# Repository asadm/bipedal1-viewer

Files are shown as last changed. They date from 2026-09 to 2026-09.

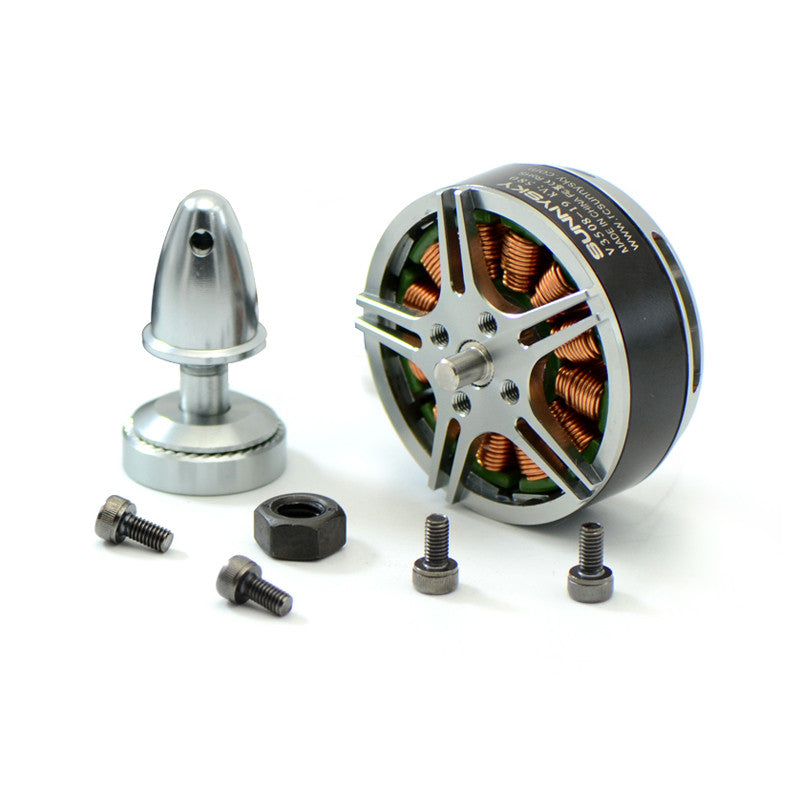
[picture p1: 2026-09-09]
clanky-v2/hardware-references/v3508-4.jpg

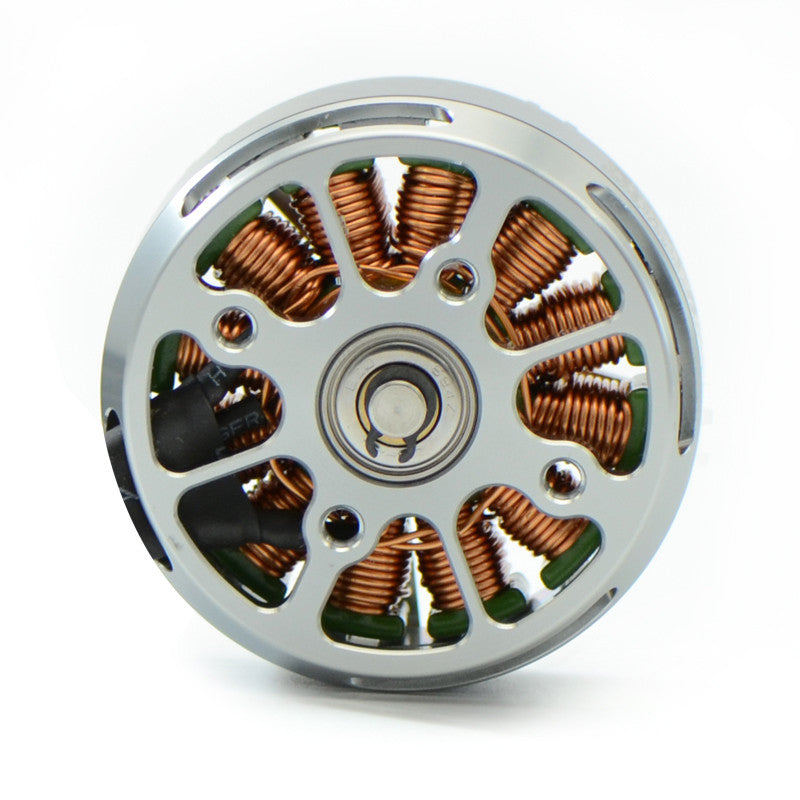
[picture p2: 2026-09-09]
clanky-v2/hardware-references/v3508-3.jpg

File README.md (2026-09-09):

# Clanky robot viewer

Built viewer, CAD assets and simulation replays, automatically updated from the
robot project on each push. `deployment.json` identifies the source revision.

- [Open the current design](https://asadm.github.io/bipedal1-viewer/)
- [Watch learned skills and programmed demos](https://asadm.github.io/bipedal1-viewer/viewer/skills.html)

The robot and policies are simulation prototypes. Physical hardware remains
unqualified; see the validation reports linked from the viewer.

Raw development records and unlinked CAD exports remain in the source robot
repository. `source-files.json` lists the files omitted from this static site.

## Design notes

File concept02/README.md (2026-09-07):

# Enclosed concept 02

[Open the new interactive design](http://127.0.0.1:8765/viewer/enclosed.html). Start the existing local server with `python3 design/viewer/serve.py` if needed. The earlier mechanism viewer remains at `/viewer/`.

This is an actual parametric solid-CAD **appearance and packaging concept** for the enclosed jumping direction. It replaces the open side plates with a rounded body, rear closure, TPU lower wrap, covered arms and an integrated fixed face. It does not yet establish a working jump transmission, balance controller, assembly sequence, strength or environmental rating.

The low pose is nominally **160 × 180 × 180 mm**, and the body rises 50 mm to approximately 230 mm overall. It retains Beni's reference width and compact height, with a shorter body. Tessellated/CAD bounding boxes may include about 0.2 mm tolerance. Every printed shape is checked for a single connected solid and a bounding box within 170 × 170 × 180 mm. Print orientation, support removal and fit still need slicer/prototype work; no functional STLs are released for this revision.

## Inspect

- Drag to orbit, scroll to zoom, right-drag to pan. Front, Side, Top and Fit reset the camera.
- The slider changes the **shared nominal arm angle**, moving the body through 50 mm while the tires stay at ground level. It is not the motor-shaft angle: reduction and spring deflection are unselected.
- Enclosed, Ghost and Cutaway show the outside or internal reservations. Cutaway removes the front shell, impact wrap, visor and right arm enclosure.
- **Locate jump drive** opens the cutaway and highlights the orange package low at the rear of the body.
- **Inside the jump drive** opens an [enlarged functional mechanism sketch](http://127.0.0.1:8765/viewer/drive.html). Crouch / Load / Extend / Retract show prescribed input/output angles. An independent left-arm slider shows that the two spring deflections need not match. A single 3:1 gear stage and helical torsion springs illustrate the force path; their dimensions, total reduction and fit are not selected. Separate damping and final bearing/retention details are not depicted.
- **One-wheel bump** places the left wheel on a 12 mm block while prescribing a level body. This demonstrates independent geometry; it does not demonstrate automatic roll leveling or a solved suspension response.
- Click any part for its role and design status. Wheels and part edges can be toggled.

The orange 34 × 74 × 68 mm volume reserves space for a rotary drive/reduction; it is **not the drawing of a selected motor**. The two gold annuli reserve independent elastic couplings. No spring internals, stiffness, preload, damping or torque capacity are established. The gray shaft indicates the proposed common drive axis. The wheel-motor, battery and controller envelopes also require final component selection and retention.

Nine printed-shape envelopes are currently modeled: two body shells, one TPU wrap, two arm/pods, two rims and two wheel-face inserts. Final rim/face integration may reduce that count; internal transmission parts and final small service details are not included. Integral rear screw-boss reservations are present, but nut/insert fits, load-spreading details, bearing supports and service access are not released.

## Files

- [Parameters](parameters.json) and [CadQuery source](build.py)
- [Normal assembly STEP](../output/concept02/beni_enclosed_normal.step), [low](../output/concept02/beni_enclosed_low.step), [extended](../output/concept02/beni_enclosed_raised.step)
- [Exterior render](../output/concept02/hero.png), [cutaway](../output/concept02/cutaway.png)
- [CAD/print-envelope manifest](../output/concept02/manifest.json)
- [Jump architecture and sizing](../jump-upgrade.md)

Rebuild from the workspace root:

```sh
.venv/bin/python design/concept02/build.py
node design/concept02/verify.mjs
/Applications/Blender.app/Contents/MacOS/Blender --background --python design/concept02/render.py
```

Verification compares browser transforms with separately posed CAD exports and checks the slider/bump range. It does not perform a full solid interference audit. The existing MuJoCo model remains concept 01, with its slow screw drive; it has not been updated to model the provisional rotary jump mechanism.

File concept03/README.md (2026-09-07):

# Component-driven jump development — concept 03

**A nominal simulated hop, not a final hardware or print release.**

Open [the interactive jump playback](http://127.0.0.1:8765/viewer/jump.html). It replays the MuJoCo rollout, with orbit camera, pause, slow motion, a time slider and takeoff/apex/landing buttons. The spring overlay shows the lengths calculated from the same recorded states. It is a mechanism illustration, not fitted production CAD.

Native MuJoCo UI:

```sh
.venv-sim/bin/mjpython design/concept03/replay.py
```

Space pauses, R restarts, S changes speed, left/right arrows step. Mouse controls use MuJoCo's standard orbit and zoom. Both viewers replay recorded states; the underlying rollout is generated by the motor/controller/physics model below.

## Selected motors and springs

Prices checked September 6, 2026. This budget covers **three motors and four springs**, not the complete robot or complete actuation system. No parts have been purchased.

| Component | Quantity | Each | Total | Source |
|---|---:|---:|---:|---|
| Waveshare DCGM-3865-12V-EN-240RPM, SKU 22346 | 2 | $9.99 | $19.98 | [Waveshare store](https://www.waveshare.com/product/robotics/motors-servos/motors/dcgm-3865-12v-en-240rpm.htm) |
| Mabuchi RS-550PC-7527, Kysan 1112389 | 1 | $12.50 | $12.50 | [Kysan listing](https://www.kysanelectronics.com/Products/SubClass.php?recordID=281) |
| MISUMI SWF12-50 | 4 | $2.28 | $9.12 | [Configured MISUMI US listing](https://us.misumi-ec.com/vona2/detail/110100185510/?HissuCode=SWF12-50) |
| **Motors + springs** | | | **$41.60** | Before shipping/tax |

The MISUMI US page was inspected in the browser with quantity 4: unit price $2.28, total $9.12. Its 1–19 price tier covers this quantity. Do not substitute the $1.20 surplus listing: that seller only listed one unit. Inventory and prices can change.

The RS-550 is a commodity power-tool motor family, but its **7527 winding matters**. A generic "12 V 550" label does not establish the same electrical performance. [Manufacturer-authored datasheet](https://www.electan.com/datasheets/mov555.pdf): 12 V, 18,200 rpm no-load, 0.421 Nm stall, 70 A stall, approximately 255 g; CCW-advanced commutation. Reverse performance is not specified.

The wheel motors are all-metal, backdrivable L-shaped geared motors. The current [Waveshare wiki](https://www.waveshare.com/wiki/DCGM-3865-12V-EN-240RPM) lists 240 rpm no-load, 4 kgf·cm rated torque at 125 rpm, 8.5 kgf·cm stall torque and a 6 mm output shaft. The official STEP and drawing archive are in `sources/`. Older mirrored wiki PDFs list a different encoder pulse count: verify the purchased revision rather than hardcoding old encoder specifications.

The spring catalog specifies 12 mm nominal OD, 6 mm nominal ID, 50 mm free length and **5.5 N/mm ±10%**. The 40% deflection column corresponds to 20 mm compression and a catalog service count of 1 million under its test conditions; it is not a robot fatigue guarantee. The 50% maximum is 25 mm. Our development travel ceiling is 20 mm, with 0.5 mm validation margins. [MISUMI catalog](https://uk.misumi-ec.com/pdf/fa/2014/P2_0365-0366_F37_EN.pdf).

## Mechanism represented by the physics

Two wheel motors balance and drive. One RS-550 drives a common shaft through an **assumed 25:1 reduction**. Each arm connects to that shaft through its own opposed spring pair. The arms can therefore move differently over bumps without independent height motors.

For each arm, a proposed constant-radius rack coupling gives:

```
x = 0.030 m × (shaft_angle − arm_angle)
spring compression = 0.010 m ± x
branch torque = 2 × 5500 N/m × (0.030 m)² × (shaft_angle − arm_angle)
```

This is 9.9 Nm/rad per branch. The 10 mm preload keeps both compression springs seated in the nominal rollout. A guided rack and arm-side sector gear must realize this relationship; their manufacturing detail is **not complete**. The illustrated coils use an approximate winding count, not manufacturer winding geometry.

The motor briefly increases shaft torque. The springs load and transmit force to the arms, which push the wheels into the ground. The body accelerates upward. After contact is lost, the drive retracts; landing compresses the suspension and the wheel controller recovers balance. There is no release latch or linear screw actuator in this model.

A 25:1 reduction, 80% transmission efficiency, rotor inertia of 1e-5 kg·m², 11.1 V supply and a 45 A current limit are **assumptions**, not selected/measured gearbox, driver or battery specifications. Reverse torque is derated to 75% as an explicit assumption; it does not constitute a validated reverse motor curve.

## Nominal result and limits

Reproduce:

```sh
.venv-sim/bin/python design/concept03/trial.py --save
.venv-sim/bin/python design/concept03/trial.py --no-jump
```

The plant has a free-floating chassis, gravity, ground/tire contacts, independent passive arm joints and three motor actuators. The controller never edits the root pose or velocity after initialization. Tendons do not impose artificial travel-stop impulses. A run leaving the compression-only spring domain fails validation.

Nominal 2.0 kg, level-ground run, 45 ms launch pulse:

| Metric | Result |
|---|---:|
| Both-wheel clearance, first flight | 52.2 mm |
| First flight duration | 150.5 ms |
| COM rise **after takeoff** | 16.6 mm |
| Spring compression range | 1.20–18.80 mm |
| Maximum body pitch | 2.55° |
| Body-ground contact | None |
| Peak jump motor current | 45 A |
| Maximum wheel torque | 0.393 Nm |
| Final pitch / forward speed at 5 s | 1.63° / 0.031 m/s |
| Approximate horizontal displacement | −102 mm |
| Jump motor copper loss over 5 s | 162 J |

**Wheel clearance is not COM jump height or proven obstacle-clearing ability.** This hop includes leg retraction. Landing rebounds occur; total airborne time across bounces is not the first flight duration. The model does not demonstrate forward obstacle traversal.

`output/report.json` contains explicit pass checks. `output/sensitivity.json` retains the one-at-a-time perturbation results, including failures. For example, 2.2 kg causes body contact; 65% reduction efficiency reduces clearance to about 31 mm; −10% spring rate violates the conservative spring margins. These are development findings, not a robust sim2real qualification.

## Work remaining before hardware release

- Detail and check reduction gears, supports, rack/sector interfaces, fasteners, spring guides and mechanical stops. Imported wheel motor geometry is available but not fitted into final arms. Concept 02's old cylindrical motor mounts do not fit these L-shaped motors.
- Finish a fitted enclosure and support structure. The simulation uses simplified collision geometry; it does not prove all actual hardware clears the enclosure or ground. The concept 02 CAD remains a separate appearance study.
- Close the mass budget using measured parts and printed geometry; 2.0 kg is currently assumed. Inertias, damping, friction, gearbox backlash and tire behavior need measurements.
- Address holding losses and motor heating. The direct, backdrivable common drive draws substantial standing current; a counterbalance or different transmission may be necessary for useful battery life. Repeated jumping is not thermally qualified.
- Select suitable current-controlled drivers, battery, conductors and fusing for measured peak demand. A 45 A software limit is not evidence that an inexpensive driver can sustain it.
- Add encoder/IMU estimation, timing delay, backlash, sensor noise and a realizable controller interface. The feasibility controller currently uses perfect simulated COM/state information, not a deployable controller or trained policy.
- Verify asymmetry, uneven ground, traction and repeat jumps. This nominal test begins symmetrically on level ground; it does not establish outdoor robustness.
- Release printable CAD only after fitting and structural checks. No claim of an unbreakable printed robot, waterproof enclosure or final working hardware is made.

## Independent powered legs option

Replacing the shared drive with one motor/reduction per leg gives **four motors total**: two wheels, two height/jump drives. Both passive spring pairs can remain, so no additional springs are inherently required. It enables commanded left/right height difference, body roll control, load redistribution and independent landing commands. Pitch balance still depends strongly on the wheel motors.

Using the same motor adds $12.50 to the motor/spring subtotal, making **$54.10** before the additional electronics and transmission. It also adds at least the 255 g motor itself. The complete mass and part-count increase depends on the final transmission. Smaller per-leg motors might reduce these penalties, but require a new selection and dynamics check; halving nominal static torque is not enough to size a motor for one-wheel landings.

Budget approximately one extra motor, one extra driver channel, one extra driven-joint sensing channel, another reduction train, extra shaft/bearing support and additional mounting geometry. These are design estimates, not a completed manufacturing BOM. Independent legs improve the available control authority; the benefit depends on developing and validating the corresponding controller. [Ascento's primary paper](https://arxiv.org/html/2005.11435v1) describes independent hip actuation and an experimental leg-angle-based inward lean mode.

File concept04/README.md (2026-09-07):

# Independent-leg jumping robot — concept 04

This is the current **four-motor development design**: one wheel motor and one leg-extension motor per side. [Open the interactive CAD and MuJoCo replay](http://127.0.0.1:8765/viewer/fourbar.html). Use **Leg sliders** to inspect each side independently, **Cutaway** to expose the drives, and **Jump → Apex** to inspect the airborne pose.

**Higher jump study:** the same hardware model with deeper crouch, a 2.6 N·m requested hip push for 54 ms and increased hip damping reaches **71.9 mm wheel clearance / 41.9 mm COM rise**. Select **Higher** in the viewer or [open it directly](http://127.0.0.1:8765/viewer/fourbar.html?jump=higher). The nominal run passes, but four of twelve sensitivity/timestep cases fail the leg travel-limit check; this is an experimental profile. Half timestep gives 71.4 mm. Peak compression is 18.23 mm and combined hip copper loss is 207.7 J over five seconds, about twice the reference run. [Report](output/higher/report.json), [sensitivity](output/higher/sensitivity.json). The [25 cm sizing study](../concept05-study/README.md) investigates the mechanical changes required for Beni-like advertised height.

The selected motor and spring models are concrete. The assembly remains a packaging study, **not a final functional print release**. The nominal physics test passes; two of eleven sensitivity cases fail. Mechanical interference, mounting, torque transmission, sealing and strength have not been qualified. No physical robot has been tested.

## What changed

The earlier three-motor shared drive is replaced with two independent leg drives. Each leg has a closed four-bar linkage: a driven crank, a passive guide and an extended lower coupler. The knee follows the linkage and has no separate motor. Each knee has one stock compression spring acting between the upper and lower members. There is no slow screw actuator, spring latch or additional jump motor.

The inspiration is the **original research Ascento**, whose optimized linkage approximates vertical wheel travel, independent hip drives set the two leg heights, and parallel springs assist the motors. Its paper also demonstrates jumping and recovery from some falls. Our dimensions, commodity brushed motors and compression-spring implementation differ substantially. Ascento used ANYdrive hip actuators, direct-drive Maxon wheel motors and SLS PA12 structure; its hardware performance cannot be assumed for inexpensive geared motors and A1-mini FDM parts. [Original Ascento paper](https://arxiv.org/html/2005.11435v1)

Beni's teardown references appear to show independently powered hip and knee joints per leg, in addition to each wheel motor: approximately six locomotion actuators. That would allow fore/aft wheel placement as well as extension. The motor inventory is inferred from [IMG_3970](../../ref/IMG_3970.jpeg), not a published manufacturer BOM. There is no evidence here that Beni derives from Ascento. Extra pose freedom is a plausible engineering reason for the added joints; Mondo's precise design rationale is not established. Our four-motor design provides independent height, not all of Beni's apparent articulation.

## Selected motors and springs

Prices checked 6 September 2026. The agreed ceiling applies to **motors and springs only**. It excludes gears, shafts, bearings, drivers, sensors, tires, battery, wiring, prints, tax and shipping.

| Component | Qty | Each | Subtotal |
| --- | ---: | ---: | ---: |
| [Mabuchi RS-550PC-7527, Kysan 1112389](https://www.kysanelectronics.com/Products/SubClass.php?recordID=281) | 2 | $12.50 | $25.00 |
| [Waveshare DCGM-3865-12V-EN-240RPM, SKU 22346](https://www.waveshare.com/product/robotics/motors-servos/motors/dcgm-3865-12v-en-240rpm.htm) | 2 | $9.99 | $19.98 |
| [MISUMI SWF10-50 compression spring](https://us.misumi-ec.com/vona2/detail/110100185510/?HissuCode=SWF10-50) | 2 | $2.18 | $4.36 |
| **Total** | | | **$49.34** |

**Hip/jump drive:** the exact RS-550 winding is specified, not an arbitrary motor bearing the same case-size name. Its 12 V sheet gives 18,200 rpm no-load, 0.421 N·m stall torque and 70 A stall current. Stall is not a continuous rating. The proposed reduction is 16:1, using two 12:48 spur stages. A purchased gearbox and metal pinion SKUs are not selected. The simulation assumes 80% transmission efficiency, rotor inertia of 1e-5 kg·m², a 35 A limit per hip and an 11.1 V supply. The motor has advanced CCW brush timing; reverse performance needs measurement. [Manufacturer-authored motor sheet](https://www.electan.com/datasheets/mov555.pdf)

**Wheels:** the selected Waveshare motor is a 12 V, 240 rpm, 42:1 metal gearmotor with encoder, nominal mass 167 g and 6 mm shaft. Its published rated point is about 0.392 N·m at 125 rpm. The CAD uses the vendor's STEP envelope. Backlash, reversal response and radial impact support remain unmeasured. The current wiki specifies 13 PPR before reduction; verify the supplied encoder revision. [Official specifications and CAD downloads](https://www.waveshare.com/wiki/DCGM-3865-12V-EN-240RPM)

**Spring:** SWF10-50 is 50 mm free length, 10 mm nominal OD, 5 mm nominal ID and **3.9 N/mm ±10%**. Use 20 mm compression as the design ceiling; the catalog's maximum is 25 mm. Catalog cycle guidance does not establish robot landing life. The spring is softer than the previous SWF12-50 selection, reducing holding current in this geometry. Both seats must swivel and retain/guide the spring without coil bind. The viewer shows illustrative guides; these parts and their mounts are not detailed in the exported CAD. [MISUMI dimensional/rate catalog](https://uk.misumi-ec.com/pdf/fa/2014/P2_0365-0366_F37_EN.pdf)

## Geometry and print size

| Dimension | Current value |
| --- | ---: |
| Crank A–C | 60.420 mm |
| Passive guide B–D | 88.115 mm |
| Lower coupler C–D | 18.839 mm |
| Knee to wheel C–E | 90.000 mm |
| Fixed B relative to hip A, x/z | 19.592 / 45.000 mm |
| Commanded hip range | 0.7–1.2 rad |
| Wheel vertical travel | 50.227 mm |
| Wheel fore/aft excursion over that range | 0.131 mm |
| Tires, nominal envelope | 100 × 30 mm |
| Track between wheel centers | 150 mm |
| CAD bounds near ride pose | approximately 174 × 180 × 215 mm |
| Compact / extended top height, nominal level pose | approximately 180 / 230 mm |
| Assumed total mass | 2.40 kg, not weighed |

The 14 current rigid printed shapes comprise two body halves, six linkage members, two rims and four large gears. Every shape is a valid single solid with each bounding-box dimension under **170 mm**, leaving margin within the A1 mini's 180 mm build volume. The largest body half is about 160 × 66 × 96 mm. This checks geometric print size; it does not validate support removal, print orientation, strength or assembly. Further mounts, spring seats, covers and retainers will change the final part count. [CAD manifest](output/cad/manifest.json)

The clamshell is 2.8 mm nominal wall thickness with integrated bolt bosses. Metal pins and shafts are allocated, but their retention, bearing support and positive torque connections are unfinished. Some member/case clearances and gear/case clearance need correction; no complete interference-free motion sweep is claimed. Purchased tires and supported wheel hubs still need selection. The outer shape is enclosed in appearance; this does not establish a dirt/water seal or outdoor impact durability.

Files: [assembly STEP](output/cad/beni_four_motor_concept04.step), [CadQuery source](cad.py), [geometry](geometry.json), [STLs and manifest](output/cad/), [browser kinematics](kinematics.mjs).

## How the jump works

1. Both hip motors retract the legs and compress the springs.
2. Both motors apply a short extension command. Motor work and spring release push the wheels against the ground, accelerating the body upward.
3. Once both wheels leave the ground, the legs retract for clearance. Wheel torque helps control pitch in flight.
4. At landing, the springs and controlled hip motion absorb energy while wheel balancing resumes. The legs return to the normal standing position to reduce holding loss.

The springs act in parallel with the leg drive. They provide useful compliance only when the transmission and controller permit joint movement; a locked hip does not give an independently moving suspension leg. The spring damping value in the model is an assumption, not a selected damper specification.

## Recorded physics results

These values come from a free-body MuJoCo rollout with ground contact, closed-link constraints, motor torque-speed/current limits and reflected rotor inertia. The root pose is initialized once and then evolves under dynamics. The web UI overlays the CAD on recorded rigid-body poses; it does not invent the airborne trajectory. The native viewer replays the same state record and is not a live policy controller.

| Nominal 5 s jump run | Measured in simulation |
| --- | ---: |
| First-flight wheel clearance | **47.89 mm** |
| COM rise after takeoff threshold | **22.68 mm** |
| First-flight duration | 165.5 ms |
| Maximum body pitch magnitude | 1.40° |
| Peak spring compression | 14.20 mm |
| Peak current per hip | 35 A |
| Peak wheel torque | 0.302 N·m |
| Maximum loop closure error | 0.0138 mm |
| Body/link ground contact | none in simplified collision model |
| Final pitch / forward speed | −1.00° / −0.012 m/s |
| Hip winding loss, combined over 5 s | 104.8 J |

Takeoff is detected when both wheel contacts are absent and both clearances exceed 2 mm. Wheel clearance includes leg retraction and is **not** the same measurement as ballistic COM rise. COM rise is measured from the sampled takeoff threshold, not extrapolated to exact contact separation. [Full nominal report](output/report.json)

The separate 15 mm step test starts with one wheel on a higher surface, with that terrain height supplied to the controller. Both wheels remain supported and maximum body roll is approximately 0.0061°. This is a stationary unequal-height balance test, not autonomous step detection or climbing. Combined hip winding loss is about 97 J over 5 s, roughly 19 W average; prolonged uneven stance needs thermal testing. [Uneven-terrain report](output/uneven/report.json)

The unchanged jump controller was checked against eleven individual parameter cases. **Nine passed; two failed:**

- Mass −10%: 54.11 mm clearance, but the hip reaches the travel-limit rejection threshold. This is not an accepted improved jump.
- Rotor inertia ×2: 36.32 mm clearance, below the 40 mm acceptance target.
- Nominal, mass +10%, spring rate ±10%, zero branch damping, 65% gearbox efficiency, 10.5 V supply, 50% reverse-torque factor and tire friction 0.4 passed these checks individually.

These are not combined uncertainties or a statistical reliability test. Successful scalar variations do not validate backlash, sensor delay, battery sag, tires, collisions or controller transfer. Failures are preserved in [sensitivity.json](output/sensitivity.json), with earlier development trials in [development_sweep.json](output/development_sweep.json).

## Sim2real and the next physical gate

The plant exposes four motor actions: left wheel, right wheel, left hip and right hip. The underlying MuJoCo hip controls are output torques; the Python `Motor` wrapper applies the proposed motor's current/voltage limits and must remain in a training environment. Directly writing unrestricted hip torques into XML controls would bypass those limits. The model includes IMU sensors and named encoder joints.

The current demonstration controller uses perfect state, including COM position and world velocity. It is not a deployable policy and no learned controller or sim2real transfer is claimed. A hardware observation interface should use IMU angular velocity and acceleration, wheel encoder positions/velocities and absolute hip output angles; a state estimator must replace simulator-only quantities. Absolute hip sensing, homing and electrical drivers remain unselected.

Before hardware release, build **one complete leg/drive module** with restrained testing. Measure motor current/torque and reverse performance, output backlash/friction, effective rotor inertia, spring force/length, print deflection and wheel impacts. Qualify supported wheel bearings, gear teeth, shaft couplings, spring guides, fasteners and end stops. The assumed hip drivers must support 35 A each briefly, and the battery must handle the combined pulse without excessive sag; no chosen driver/battery yet establishes that capability. Structural and thermal qualification are separate from a successful dynamics rollout.

Feed the measured ranges into domain randomization for mass/COM/inertia, spring rate, damping, friction, gearbox loss/backlash, supply voltage, sensor noise and delay. Establish restrained balancing before changing height, then test low-energy hops and progressively harder landings. The original [transfer plan](../sim/README.md) remains useful process guidance, but its earlier three-actuator plant is superseded by this model.

## Reproduce

Run from the workspace root:

```sh
.venv-sim/bin/python design/concept04/trial.py --save
.venv-sim/bin/python design/concept04/sensitivity.py
.venv-sim/bin/python design/concept04/verify.py
node design/concept04/verify.mjs
.venv/bin/python design/concept04/cad.py
python3 design/viewer/serve.py
.venv-sim/bin/mjpython design/concept04/replay.py
```

The kinematics checks compare 121 independent left/right poses against the MuJoCo tree and spring sites, 101 poses against the browser linkage solver, and 25 independent browser pose pairs. All pass to numerical precision; these tests do not check solid-part interference.

For the unequal-height case, import `parameters` and `run` from `design/concept04`, set `p['left_terrain_m']=0.015`, then call `run(p, jump=False, save=True, name='uneven')`. Native replay accepts `--uneven`. Space pauses, R restarts, S changes speed, arrow keys step, and the mouse orbits. Installed environments use MuJoCo 3.3.7 and CadQuery 2.6.1.

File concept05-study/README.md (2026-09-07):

# Concept 05: longer travel, four motors

[Open the new design and jump viewer](http://127.0.0.1:8765/viewer/longstroke.html) · [Open the height sliders](http://127.0.0.1:8765/viewer/longstroke.html?mode=pose) · [Assembly STEP](output/cad/beni_concept05_long_stroke.step)

This version implements the longer linkage, two independent 24:1 hip drives, SWF12-50 springs and enclosed wheel-motor housings. The nominal MuJoCo run achieves **68.9 mm clearance under both wheels**, lands, and recovers over an eight-second record. **The 250 mm jump target has not been reached.** Three of twelve uncertainty/timestep cases fail. This is development CAD and simulation, not a validated print-and-build robot.

## Inspect and replay

- **Jump replay:** play, pause, scrub, choose playback speed, or jump to Crouch / Takeoff / Apex / Land / Settle. The full recovery is retained.
- **Inspect travel:** move the common extension slider or enable independent left/right sliders. Compact / Ride / Extended / Split presets are available.
- **Cycle travel:** prescribed motion for inspecting the mechanism, not a simulated jump.
- **Compare:** show concept 04 beside concept 05 at the same fraction of their respective travel ranges.
- **Enclosed / Cutaway / Physics:** view the CAD exterior, internal drive, or simplified MuJoCo geometry at the same pose. Drag to orbit; scroll to zoom.

The new viewer loads its own CAD and simulation record. It does not relabel the earlier 72 mm replay as a result for this mechanism.

## Mechanism and package

| Item | Concept 05 |
| --- | --- |
| Locomotion motors | 2 wheel motors + 2 independent hip motors |
| Linkage per leg | Driven crank, passive guide, extended lower coupler; no knee motor |
| Vertical wheel travel | 99.81 mm |
| Fore/aft wheel excursion | 6.04 mm |
| Hip sweep for CAD inspection | 0.35–1.50 rad |
| Crank / guide / coupler / knee-to-wheel | 64.482 / 83.502 / 28.224 / 119.119 mm |
| Hip reduction | 24:1, two stages: 12:48 and 12:72, module 1 |
| Spring seats | 43 mm back from knee on crank, 25 mm along lower link |
| Maximum geometric spring compression | 18.53 mm; 20 mm chosen design limit |
| Compact CAD bounds | Approximately 212 × 180 × 180 mm |
| Extended CAD bounds | Approximately 159 × 180 × 280 mm |
| Printed pieces | 16, largest exported axis 169.54 mm |
| Tire envelope | 100 × 30 mm, tread illustrative; tire SKU unselected |

The motor housings integrate into the two lower links. Two removable rear lids provide motor insertion access, increasing the earlier 14-piece count to 16. Moving the wheel motors 6 mm inward clears their broad gearboxes from the tires while keeping the 180 mm overall width. Motor/housing solid overlap is zero in both local CAD checks. That is a limited component check, not a complete assembly interference sweep.

All printed solids are valid, connected, and fit a conservative 170 mm box without needing diagonal placement in the final layout. [CAD manifest and print dimensions](output/cad/manifest.json), [STL files and meshes](output/cad/). Print orientation, supports, fastening, shaft clamps, bearing retention, gear durability, sealing, cooling and strength still need work. The complete solid printed volume is approximately 514 cm³; this is not a slicer-derived finished mass. Springs and guide hardware in the web view are illustrative and are not detailed spring assemblies in the STEP.

## Selected parts and budget scope

| Component | Quantity | Part | Prior unit price |
| --- | ---: | --- | ---: |
| Hip motor | 2 | Mabuchi RS-550PC-7527 / Kysan 1112389 | $12.50 |
| Wheel motor | 2 | Waveshare DCGM-3865-12V-EN-240RPM / SKU 22346 | $9.99 |
| Spring | 2 | MISUMI SWF12-50 | $2.28 |
| Motors + springs subtotal | | | **$49.54** |

These are previously checked price estimates, not a new quotation. Transmission hardware, drivers, battery, electronics, bearings, tires, fasteners, printing, tax and shipping are additional. The 24:1 gearbox is custom development geometry; its metal pinions and torque interfaces are not yet selected or qualified.

The SWF12-50 is a 50 mm free-length, 12 mm OD, 6.5 mm nominal ID spring with nominal rate 5.5 N/mm and ±10% rate tolerance. The chosen 20 mm compression limit is below the catalog maximum of 25 mm. A retained spring guide must accommodate the unloaded gap when seat separation exceeds 50 mm; the spring cannot pull the leg together. [MISUMI catalog](https://uk.misumi-ec.com/pdf/fa/2014/P2_0365-0366_F37_EN.pdf), [spring purchase page](https://us.misumi-ec.com/vona2/detail/110100185510/?HissuCode=SWF12-50).

The hip motor is modeled from its 12 V, 18,200 rpm no-load and 0.421 N·m / 70 A stall points. Its advanced commutation means reverse performance is uncertain. [Motor supplier](https://www.kysanelectronics.com/Products/SubClass.php?recordID=281), [manufacturer datasheet](https://www.electan.com/datasheets/mov555.pdf).

The wheel motor uses the manufacturer's 240 rpm no-load, 0.392 N·m at 125 rpm rated and approximately 0.834 N·m stall figures. Its official STEP is included in the CAD. [Waveshare product](https://www.waveshare.com/product/robotics/motors-servos/motors/dcgm-3865-12v-en-240rpm.htm), [documentation](https://www.waveshare.com/wiki/DCGM-3865-12V-EN-240RPM).

## Measured simulation result

| Quantity | Nominal run |
| --- | ---: |
| Minimum clearance of the two wheels at first-flight apex | 68.93 mm |
| First flight duration | 216.75 ms |
| COM rise after takeoff detection | 43.38 mm |
| Peak body pitch during complete run | 20.50° |
| Final pitch after 8 s | −1.18° |
| Final forward speed | −0.062 m/s |
| Final wheel contact | Both wheels |
| Peak spring compression | 13.77 mm |
| Peak modeled hip current | 35 A per motor |
| Hip range during complete run | 0.455–1.243 rad |
| Maximum linkage closure error | 0.0254 mm |
| Body-to-ground contacts | None in nominal run |
| Modeled combined hip copper loss over 8 s | 158 J |

[Nominal report](output/jump/report.json), [recorded trajectory](output/jump/trajectory.json), [MuJoCo plant](output/jump/plant.xml), [complete parameters](output/jump/parameters.json).

The replay uses a free-floating rigid-body model, gravity, four motor commands, closed-loop linkage constraints and real contact dynamics. Body motion is not animated by a height script. The browser CAD follows recorded body poses. The slider mode is explicitly separate prescribed kinematics.

The 2.4 kg mass assumption is retained from concept 04. No result was obtained by silently reducing mass to the aspirational 1.75–2 kg target. The revised lower-link inertial allocation includes extra housing mass. Motor rotor inertia (1e−5 kg·m²), 80% drive efficiency, 11.1 V supply, 35 A per-hip current limit, reverse torque factor, friction and branch damping are assumptions, not measurements. The 24:1 drive reflects 2.25 times the rotor inertia of the former 16:1 drive.

## What fails, and what comes next

Nine of twelve nominal/uncertainty/timestep cases pass the existing jump, landing, travel, spring and recovery checks. **Spring rate +10%, zero assumed branch damping, and tire friction 0.4 fail through body contact and loss of recovery.** Halving the timestep gives 69.03 mm and passes. [Full uncertainty results](output/jump/sensitivity.json).

The earlier concept-04 experimental run reached 71.9 mm. The new travel and stronger drive do not yet improve that measured result. Aggressive launch settings in this geometry caused overextension or poor recovery. The selected replay demonstrates a smaller controlled jump in the nominal model; it is not a 25 cm performance claim or a robust outdoor policy.

Important model limits: internal assembly self-collision is disabled, the collision model is simplified, and the controller reads perfect state. Driver/battery delivery, thermal duty, detailed mounting, gearbox losses/inertia, backlash, landing strength, seals and real tire behavior remain unqualified. Nothing here establishes that the printed robot is unbreakable or ready for sim2real deployment.

The [historical energy/geometry study](sizing-notes.md) explains the approximate 8–11 J mechanical-input scenarios behind the 250 mm target. More travel alone is insufficient: drive inertia, useful push work, tucking, landing control and mass must be optimized together. Next engineering gates are a complete interference/mounting design, a single-leg test rig to measure the motor/gear/spring system, and simulation with measured parameters, sensor noise, delay, backlash and randomized terrain before policy transfer.

## Weight versus drive experiment

The user asked whether to increase motor power. A bounded comparison retains the accepted controller and timing, except for the explicitly stronger push command. These runs do not replace the viewer's accepted nominal record.

| Change from nominal | Wheel clearance | Current checks |
| --- | ---: | --- |
| Nominal: 2.4 kg, 24:1, 35 A, 3.9 N·m push request | 68.93 mm | Pass |
| Mass reduced to 2.0 kg | 67.26 mm | Pass |
| Current limit 45 A, same push command | 69.67 mm | Pass |
| Current limit 45 A, push request increased to 5.0 N·m | 91.93 mm | Fails: body contact and recovery |
| Assumed rotor inertia halved, same commands | 99.96 mm | Fails: body contact and recovery |
| Reduction changed to 20:1, same commands | 69.13 mm | Pass |
| Reduction changed to 16:1, same commands | 63.35 mm | Pass |

[Full experiment inputs and results](output/drive_diagnostic.json). Reproduce with `.venv-sim/bin/python design/concept05-study/drive_diagnostic.py`. Ratios and rotor inertias in this table are hypothetical dynamics variants, not additional CAD releases or measured motor properties. Every variant would need its own controller optimization before comparing achievable maximum jump heights. In particular, the mass result does not imply that lighter robots inherently jump lower.

The 24:1 reduction increases reflected motor inertia by 2.25× relative to 16:1. Near the end of the nominal push, each hip reaches approximately 20 rad/s. With the assumed rotor inertia, both rotors then store about 2.3 J, compared with approximately 4.0 J positive hip work during the 60 ms push (estimated from the 5 ms recorded samples). Braking and recoil timing therefore matter alongside peak torque. Higher current with an unchanged torque request barely helps; commanding more torque lifts the robot further but loses the accepted landing. The 35/45 A limits are simulation assumptions, not qualified motor, battery or driver ratings.

The next step is coordinated takeoff, braking and landing optimization for the drive candidates, followed by measurement on the single-leg rig. A larger motor or higher current alone is not demonstrated to meet the 250 mm requirement.

## Beni reference comparison

[Updated teardown analysis](../../research/beni-jump-from-references.md) explains the visible brushless hip and knee drives, belt stage, spring assistance and metal load path. Beni is not established to share this design’s motor characteristics or reduction. The analysis also records the sizing and selection gates for the 250 mm target.

## Reproduce

From the workspace root, using the existing environments:

```sh
# Regenerate the accepted record and its uncertainty/timestep checks.
.venv-sim/bin/python design/concept05-study/validate.py

# Export CAD/STEP/STL using that record's parameters.
.venv/bin/python design/concept05-study/cad.py

# Check 121 independent MuJoCo poses and 101 browser reference angles.
.venv-sim/bin/python design/concept05-study/verify.py
node design/concept05-study/verify.mjs

# Serve only the design directory on localhost.
python3 design/viewer/serve.py

# Optional native MuJoCo replay, including all eight seconds of recovery.
.venv-sim/bin/mjpython design/concept05-study/replay.py
```

Controller exploration is retained in `tune.py`, `recovery_search.py` and their output reports, including failures. `size_jump.py` reproduces the original energy/geometry sizing. The final browser and MuJoCo kinematic checks agree to numerical precision; they do not qualify solid-part interference or material strength.

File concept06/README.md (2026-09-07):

# Concept 06 — brushless, spring-assisted independent legs

[Current internal-knee validation](validation.md): 121.8 mm nominal simulated jump; a delayed-state travel failure and structural/sealing failures prevent hardware release. [Open its replay](http://127.0.0.1:8765/viewer/validation.html).

Latest packaging: [full robot with enclosed passive knee links](http://127.0.0.1:8765/viewer/internal.html), with [design notes](internal-full.md). This uses revised linkage geometry and round V2806 wheel drives; the MuJoCo results below belong to the earlier drivetrain.

[Open the design and recorded jump](http://127.0.0.1:8765/viewer/brushless.html). On this network: [192.168.86.226:8765](http://192.168.86.226:8765/viewer/brushless.html). The server now defaults to `0.0.0.0` and serves only `design/`.

The nominal free-floating MuJoCo simulation achieves **177.6 mm clearance under both wheels**, lands, and recovers. The previous concept achieved 68.9 mm. **250 mm remains unmet.** This is a development design, not a hardware-demonstrated jump or a manufacturing release.

## What changed

- Two SunnySky X2216 V3 **880KV long-shaft** brushless hip motors replace the RS-550s. Four motors total; each knee remains passive.
- 20:1 reduction: 12:48 followed by 12:60. The two large gears per side remain printed concepts; pinions, shafts, bearings and torque interfaces need metal.
- The 99.8 mm independent leg travel, SWF12-50 springs, enclosed wheel motors and nominal 100 × 30 mm tires remain.
- Accelerating extension is specified in **vertical wheel travel**, then converted to hip angle and speed. Current/voltage limits constrain the actual motion.
- A ten-height LQR schedule controls ground balance using an approximate wheeled-pendulum model. A launch wheel-torque bias reduces takeoff rotation. Flight uses leg retraction and wheel attitude control. On descent, the legs prepare for touchdown; measured contact switches to softer landing gains before returning to ride height.
- No passive branch damper is assumed. Landing damping is commanded through the hip motors. Real friction remains unmeasured.
- Mass is **2.10 kg assumed**: 2.40 kg baseline − 0.375 kg motor savings + 0.075 kg allowance for changed drives/encoders. This is not a measured assembly mass.

## Ascento: the useful precedent

The [original Ascento paper](https://arxiv.org/html/2005.11435v1) describes two hip and two wheel motors, a three-bar leg mechanism with nearly vertical wheel motion through the body centre of mass, and parallel torsion springs. Its 10.4 kg prototype uses 40 Nm peak hip actuators and 3.5 Nm peak wheel drives, with 350 mm leg-height range and a reported 0.4 m maximum jump. Balance gains are scheduled at ten leg heights. Its jump sequence combines retraction, synchronized extension, flight retraction and compliant landing with contact detection. Its structural printing process was PA12 SLS.

We adopt those mechanism and control principles, using our own geometry, controller and motor model. Our compression springs, geared hobby motors, smaller stroke, weak geared wheel drives and FDM parts are materially different. Our geometry's wheel path has about 6 mm of fore/aft variation; it is not perfectly vertical through the moving system COM. An Ascento result does not validate this robot or its A1-mini prints.

## Selected motors and springs: $75 ceiling

| Part | Quantity | Each | Subtotal | Evidence |
|---|---:|---:|---:|---|
| SunnySky X2216 V3 880KV **long shaft**, SS-XV3-X2216-L-880-V3 | 2 | $24.99 | $49.98 | [Manufacturer product](https://sunnyskyusa.com/products/sunnysky-x2216-v3-brushless-motors-long-shaft-version); official variant JSON saved under `sources/`, available when checked September 6, 2026 |
| Waveshare DCGM-3865-12V-EN-240RPM, SKU 22346 | 2 | $9.99 | $19.98 | [Manufacturer product](https://www.waveshare.com/product/robotics/motors-servos/motors/dcgm-3865-12v-en-240rpm.htm), [specifications](https://www.waveshare.com/wiki/DCGM-3865-12V-EN-240RPM) |
| MISUMI SWF12-50 compression spring | 2 | $2.28 estimated | $4.56 estimated | [Configured part](https://us.misumi-ec.com/vona2/detail/110100185510/?HissuCode=SWF12-50), [manufacturer catalogue](https://uk.misumi-ec.com/pdf/fa/2014/P2_0365-0366_F37_EN.pdf) |
| **Motors + springs** | | | **$74.52 estimated** | **$0.48 margin. Spring checkout price has not been reconfirmed.** |

This is the agreed motors-and-springs subtotal. It excludes encoders, FOC drivers, battery, wheel drivers, transmission hardware, tires, printing, tax and delivery. No order was placed. The long-shaft version costs the same as the short-shaft version and exposes a 3.175 mm shaft for the motor pinion, avoiding a separate rotor-flange adapter. Do not substitute the older non-V3 X2216: its specifications differ.

The V3 880KV manufacturer specification gives 27.7 mm diameter, 34 mm body length, 67.5 g, 89 mΩ resistance, 0.5 A no-load current at 10 V and 32 A/30 s with propeller cooling. The spring is 50 mm free length, 12 mm OD, nominal 5.5 N/mm ±10%; our design limit remains 20 mm compression, below the catalogue maximum of 25 mm.

**The driver cost matters.** An ordinary sensorless RC speed controller is insufficient for loaded, stationary joint torque and controlled reversal. Each hip needs rotor sensing and bidirectional current-controlled FOC. The [ST B-G431B-ESC1](https://www.st.com/en/evaluation-tools/b-g431b-esc1.html) is a possible development platform with sensor connections and a stated 40 A peak tested with forced airflow; the [ST store](https://estore.st.com/en/products/evaluation-tools/product-evaluation-tools/mcu-mpu-eval-tools/stm32-mcu-mpu-eval-tools/stm32-discovery-kits/b-g431b-esc1.html) lists about $39 per board at quantity two. That is roughly $78 for the pair, separately, before encoders and integration. It is not a qualified sealed-joint drive selection.

## Recorded result and validation

The viewer uses `output/jump/trajectory.json`: real recorded body transforms from the four-actuator MuJoCo plant. The interface's height sliders and Cycle travel mode are explicitly kinematic.

| Nominal metric | Result |
|---|---:|
| First-flight minimum-wheel clearance | 177.585 mm |
| COM rise after detected takeoff | 130.822 mm |
| Takeoff / first landing | 1.389 / 1.73525 s |
| Flight duration | 346.25 ms |
| Maximum absolute pitch over eight seconds | 11.283° |
| Final pitch / forward speed | −2.098° / −0.0267 m/s |
| Both wheels in contact at end | Yes |
| Body-ground contact | None |
| Actual hip angle range | 0.4021–1.3664 rad |
| Maximum spring compression | 16.134 mm |
| Peak hip current, DC-equivalent model | 32 A per motor |
| Maximum closure error | 0.0834 mm |
| Peak combined hip mechanical output power | 414.6 W |
| Peak combined hip DC-bus current estimate | 63.7 A |
| Hip copper loss / net electrical input, full 8 s | 44.8 J / 53.1 J |

The 9 Nm `push` value in the controller is a requested-torque ceiling, **not achieved motor torque**. The electrical envelope limits positive output to roughly 5.5 Nm per hip at low speed, falling with speed/voltage. The launch wheel bias is also clipped by each wheel motor's 0.45 Nm and speed envelope.

**All 14 nominal/individual-variation checks pass**: nominal, mass ±10%, spring rate ±10%, added branch damping, 65% gear efficiency, twice rotor inertia, 10.5 V supply, −20% motor constant, twice resistance, 24 A current limit, friction 0.4, and half timestep. Clearances span **137.6–177.6 mm**. Half timestep gives 176.1 mm. These are individual changes, not a combined worst-case test or success-rate claim.

The feasibility checks require >40 mm jump, landing, no body collision, spring compression <19.5 mm, closure <0.1 mm, no hip end stop, small final pitch/roll/speed and no solver/motor-envelope warnings. `target_250mm_reached` is separately **false**. Passing feasibility is not passing the 250 mm requirement.

The Python/MuJoCo geometry check covers 121 independent leg-pose pairs; the JavaScript check compares 101 Python reference angles and 25 independent pose pairs. Errors are at numerical precision. CAD checks validate solids, connected prints and 170 mm axis envelopes; they do not prove strength or complete assembly clearance.

## Model and build limits

The BLDC model is DC-equivalent: reciprocal Kv is used for both torque and back-EMF constants, with current/voltage limits, winding loss, electrical lag, directional transmission loss and reflected inertia. Vendor battery-current, phase-current and resistance conventions are not sufficient to identify a FOC motor model. The uncertainty checks bound some consequences but cannot replace torque, resistance and back-EMF measurements.

Rotor inertia is an estimate of 4×10⁻⁶ kg m², approximately a 21 g thin ring at 13.8 mm radius; it is not published manufacturer data. The 20:1 reduction reflects this as 0.0016 kg m² at each hip, plus a 0.00008 kg m² gearbox allowance. The simulated rotors briefly store about 2.43 J combined, so arbitrarily deleting rotor inertia would substantially exaggerate jump performance.

The supply is a prescribed loaded voltage, not a battery impedance model. A real 3S battery and wiring must deliver approximately 64 A peak for the hips plus wheel/electronics demand and accept regenerated energy. The 68 × 34 × 26 mm battery volume is an allocation, not a selected or tested battery. FOC boards, cooling, encoder mounting and wiring still need packaging.

Internal self-collision, gearbox backlash, sensor noise, control latency, thermal duty, waterproofing, fatigue and printed tooth strength are not qualified. The 16 printed concepts fit A1-mini-size envelopes, but spring retainers/guides, bearing carriers, shaft torque connections, fastener capture, motor retention and seals are not a complete build release. The 100 mm tire is a geometry/physics allocation, not a purchased tire selection. No claim of unbreakability or off-road jump reliability is made.

## Next hardware gate and route to 250 mm

1. Build one instrumented hip/leg assembly, with metal torque interfaces and spring retention. Measure current-to-torque, rotor inertia, loaded voltage, backdrive loss, backlash and spring force versus angle.
2. Reconcile the mass/COM ledger with slicer output and weighed motors, tire assemblies, battery and electronics. Recalculate gear/shaft/bearing and landing loads before releasing structural prints.
3. Feed measurements into this MuJoCo plant. Add actual controller sampling, encoder/IMU noise, latency, battery impedance and backlash before RL or policy transfer; randomize measured uncertainties.
4. Test restrained takeoff/landing and balance, then progressively higher jumps. The simulation shows why coordinated launch and landing are useful, but does not establish hardware performance.

At present the 250 mm objective is short by about 72 mm. A simple energy calculation gives about 1.49 J extra COM energy at 2.1 kg for another 72 mm, but this is only an orientation/tuck-preserving estimate, not a guarantee of extra wheel clearance. Taller jumps also need low launch angular momentum, sufficient stroke and a landing the wheel drives can recover from. Raising current alone is not a validated solution; the selected motor is already at its published 32 A/30 s current figure, under very different cooling conditions.

## Reproduce

From the workspace root:

```sh
.venv-sim/bin/python design/concept06/validate.py
.venv-sim/bin/python design/concept06/verify.py
node design/concept06/verify.mjs
.venv/bin/python design/concept06/cad.py
python3 design/viewer/serve.py --host 0.0.0.0 --port 8765
```

Native MuJoCo playback:

```sh
.venv-sim/bin/mjpython design/concept06/replay.py
```

Space pauses, R restarts, S changes speed, arrows step. Both native and browser viewers replay recorded physics; they are not running a live robot policy. Earlier search outputs are diagnostics from controller development, sometimes with different parameter assumptions, and are not accepted results. `validate.py` regenerates the selected final run with the current documented plant and controller.

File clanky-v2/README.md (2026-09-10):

# Clanky V2 — reference-led redesign in progress

The prior wheel work is committed locally as `37fc29e`. Its verified jump remains
at http://localhost:8765/viewer/wheel.html?scene=robot&motion=jump .

The current integrated assembly is at http://localhost:8765/viewer/v2.html . Its
default jump uses the 340-part detailed CAD and a 2.608 kg estimated mass:
264–265 mm wheel clearance, with a settled landing at both tested timesteps.
The dropdown also offers standing balance, programmed 15° cross-slope driving,
experimental flip recordings and manual poses with shared and individual leg
sliders. Exterior, Cutaway and Physics follow the same recording. Earlier
learned/recovery recordings retain their original CAD and do not qualify this
new plant. See [detailed dynamics and limits](detail-native/README.md).
Flexible wiring, cooling, print tolerances and structural loads remain open.
**This is development CAD and nominal simulation, not a verified robot.**
The latest navigation/viewer changes are local and have not been pushed.

The preceding [terrain-trained actor](training/TERRAIN_DRIVING.md) adds a local
**Learned terrain · +10° cross slope** replay. It improves the fixed terrain
screen from 2/13 to 5/13 paired passes; rocks/longitudinal slopes and a flat-stop
regression remain open. The original flat-driving actor remains separate.

The new [detailed-CAD navigation campaign](detail-native/terrain-navigation/README.md)
passes its programmed flat, +10° hill and +15° cross-slope demonstrations at
both timesteps. One new imitation fit passes 8/10 held-out physical evaluations:
flat, ±5° and +9°. The −9° valley pair stays upright but falls short of the
distance target. The **Learned hills · latest CAD** viewer mode displays the
passed +9° run. Its external navigator still uses perfect simulator pose.

## Preceding native dynamics development — 2026-09-09 UTC

A [native V2 plant](native/README.md) follows the preceding viewer composition,
including the aligned springs and the more detailed left hip. Its CAD and
component-prior estimate is 2.489 kg, including 0.805 kg of prints; these are
unweighed, unsliced values. The first 289 independent-pose, spring-energy and
two-timestep passive checks pass. Powered trials keep their own reports and
do not transfer the earlier R2 jump evidence. The integrated RS05 remains a
separate proposal, not the drive used in this native baseline.

The displayed jump now clears 264.31 mm at 0.25 ms and 264.25 mm at 0.125 ms
physics timesteps, with 195 mm COM rise and a settled landing over the last two
seconds of each eight-second trial. A preparatory lean, revised launch braking,
leg tuck and earlier landing preparation achieve this on the unchanged plant.
The first 81 mm viewer experiment is preserved at commit `6d3f645`.

This meets the **nominal** 250 mm jump target, but the sensitivity grid passes
only four of ten cases: nominal and higher-guide-friction cases at both
timesteps. A ±20% mass change or a 9.6 V supply fails the height and/or landing
checks. The full jump requirement remains incomplete. See `native/README.md`
and `native/jump-validation.json`; no hardware or other-skill qualification follows.

## Current body and wiring update — 2026-09-08

The user requested a single body with a flush sensor region, room for the battery
and Raspberry Pi, and a **loose D435i-sized camera fit**. `body_package.py` replaces
the former neck/eye pod with two body prints. The camera's native optical face is
exposed through an opaque surround; no extra tinted optical window is specified.

| Reservation | X × Y × Z, mm | Basis |
|---|---:|---|
| Camera and side USB | 45 × 120 × 40 | [D435i: 90 wide × 25 deep × 25 high](https://www.realsenseai.com/products/depth-camera-d435i/) |
| Pi, cooler and plugs | 110 × 78 × 32 | [Pi 5: 85 × 56 PCB](https://datasheets.raspberrypi.com/rpi5/raspberry-pi-5-mechanical-drawing.pdf), approximate cooling/connector envelope |
| Battery | 76 × 42 × 32 | Retained 68 × 34 × 26 pack placeholder, SKU/discharge capacity unselected |
| Control electronics | 70 × 42 × 24 | Allocation, drivers not selected |

The side USB allowance is separately modeled as 25 × 20 × 20 mm inside the
camera reservation. This does not select a cable or prove its bend radius. Exact
mounting, Pi cooling/airflow, camera field of view and weather sealing remain open.
`check_body_package.py` checks exact CAD cavity containment, pairwise separation
of all four reservations, and the component envelopes within their own bay.

**Width tradeoff:** the 168 × 126 × 84 mm body is substantially wider than the
previous 66 mm body. Each complete leg/module moves 36 mm outboard relative to
commit `5c43860`, retaining its internal stack and all joint ranges. Track becomes
232 mm; the complete envelope is 252 mm wide. The approximately
199 × 252 × 166 mm fold **does not meet the former 180 mm working width target**.
This is a roomy packaging iteration, not a claim that the original size is retained.
All sixteen current connected prints still fit the A1 Mini's dimensional envelope;
orientation, support, plate count and strength are not yet qualified.
Printed volume is 542.3 cm³ versus 422.8 cm³ at the compact checkpoint. This is
volume, not a measured print weight or complete-robot mass.

`wiring_package.py` adds two integral passages in each thigh (6 mm power and
4 mm feedback bores), a 12 × 3.5 mm flat-harness passage in each shin, a 6 mm
motor lead exit and a 5.2 mm encoder-cap exit. There are **no extra printed covers**.
Feed unterminated wires through the shin passage before fitting connectors.
Wire gauge, insulation, current heating, grommets, strain relief and waterproofing
are not selected. The orange/blue viewer curves are **route sketches**: their
lengths vary with pose and they are not validated flexible cables. Do not treat
the rigid assembly collision pass as a cable-pinch or flex-life result.

Keep one rotor position sensor at each BLDC wheel motor, inside its encoder cap.
It supports low-speed/zero-speed torque control and wheel-speed estimation via
the gear ratio. An additional wheel-output encoder is not included at this stage;
gear backlash remains an estimation/control limitation. The encoder board shown
is still an allocation, not a sourced functional electronics design.

Rebuild/check in this order (CAD uses the project CadQuery environment; collision
and mesh checks use trimesh/python-fcl):

```text
.venv/bin/python design/clanky-v2/assembly.py
.venv/bin/python design/clanky-v2/check_body_package.py
python design/clanky-v2/check_wiring_package.py
python design/clanky-v2/check_assembly.py
python design/clanky-v2/assembly_properties.py
```

The new passage material has its own all-part/rotation-envelope check, including
inside each wheel module. Previously checked nominal wheel/bearing interfaces
are retained; the new wire ports remove material. Strength and fatigue need a
fresh review. Hip drives, grounded tie support, joint retention and final mass
remain unfinished. No R2 jump or learned-skill evidence transfers to this revision.
The first duct union produced two nonmanifold edges at a bore tangent to the
original thigh wall. Moving the bore plane 0.5 mm removes that zero-thickness
junction in the CAD; no mesh holes were filled. The initial failure is preserved
in `assembly-properties-before-wire-junction-fix.json`. The corrected 175 meshes
are watertight and consistently wound, with maximum volume error about 0.206%.

## Requirements and current direction

The latest [output-joint and case study](hip-output/README.md) is visible at
http://localhost:8765/viewer/v2.html?study=output&view=cutaway . The stock drive
now runs 15→60 then 20→80 teeth, retaining 16:1 and the same four gear purchases.
The earlier large intermediate gear interfered with the output spindle and
neck. The corrected layout clears the moving legs over 405 sampled poses;
the changed left joint/case has 987 passing exact material checks. Actual gear
engagement remains excluded and unvalidated. The case and bearing supports
are integral to the existing body prints; all three changed prints have CAD
bounds below 180 mm per axis. This is not a sliced plate or strength result.

Next work remains substantial: functional motor and compound couplings,
gear phase/backlash, bearing/shaft retention, case closure and tool access,
bilateral integration, loads, sourced electronics, measured mass/inertia and
motion qualification of the new native V2 plant. Required dynamic skills are
still unverified. The
[integrated-actuator comparison](integrated-hip/README.md) now includes official
RS05 CAD, the loaded 48 V curve and a lower-voltage EduLite sizing estimate.
At 48 V the prescribed 250 mm ballistic COM-rise load fits the RS05 curve at
2.2/2.64 kg, but that is not a wheel-clearance jump or battery-range validation.
The existing fixed spindle cannot pass through the RS05; an inboard tie route
clears a proposed neck envelope in 405 planar samples. Its anchor, moved knee
lever, full mounting structure and power system remain unfinished. Neither
integrated actuator is selected, and the custom drive remains the fallback.

The separate [supported-hip study](hip-joint/README.md) develops a left spindle,
paired bearings and retained hidden tie pivot without modifying the main viewer.
Its contact and exact-CAD diagnostics are separate from the current assembly
checks. It also exposes previously omitted lateral spring-slider loads; a
physical anti-rotation/retention interface is required before adoption. There is
still no complete V2 drive or dynamic motion result.

The subsequent [aligned-spring study](coaxial-spring/README.md) replaces the
eccentric stem with a curved steel link and directly guided printed piston.
Its optional local viewer is http://localhost:8765/viewer/v2.html?study=spring .
The left-side study passes 405 sampled poses with 896 exact-CAD follow-up checks
and finite piston support/anti-rotation probes. It keeps 16 connected prints;
complete spring retention, tribology, fastener loads and the hip drive remain
unqualified. This is separate development geometry, not a new motion replay.

`requirements.json` retains the full objective: Beni-like enclosed construction,
folding, big jumps, fall recovery, speed, one-wheel balance, off-road suspension,
low cost, mostly A1 Mini printable parts, low assembly complexity and sim2real.
Four locomotion motors remain preferred. Six is a fallback to be justified by
comparative required-motion evidence, not a response to one failed controller.
The numeric targets are labeled as working engineering targets where the user
has not specified an exact acceptance value.

All 15 supplied images were reviewed again. `reference-sheet.jpg` is a contact
sheet; originals in `ref/` remain unchanged. In particular:

- `IMG_3967–3969` show the outer-leg belt and its root-mounted motor.
- `IMG_3970` and `IMG_3973` show a second root motor and the knee mechanism;
  the embedded caption explicitly identifies an inner brushless knee motor.
- `IMG_3974` shows an internal reduction lever. The spring cylinder is behind
  the thigh in `IMG_3970/3973`.
- `IMG_3972` identifies metal thigh structure. White covers are not evidence
  that all the load-bearing parts are plastic.
- The assembled side/folded/airborne images guide proportions and packaging;
  perspective photographs do not supply calibrated dimensions or joint limits.

The references support approximately six locomotion motors on Beni, excluding
the head. This is a teardown inference, not its complete manufacturer inventory.
Mondo lists [215 ×180 ×180 mm and 1.75 kg](https://mondorobotics.com/), without
identifying the dimensioned posture. We use that envelope as a folded-package
working target. The latest requested sensor packaging uses a flush body opening,
with no separate head. It exceeds that working width target as stated above.

[Ascento](https://arxiv.org/html/2005.11435v1) establishes four-motor spring-assisted
jumping, but excludes side-rest recovery in its original controller.
[STRIDE V2's designer](https://www.alex-hattori.com/blog/wheeled-biped-v2) explains
why independently controlling reach and extension helped recovery, with added
cost and complexity. Neither reference establishes our proposed performance.

## Architecture search completed so far

The previous recovery redesign retained the 64.5/119.1 mm links. This study
also changes link lengths and the knee phase. It keeps all failures and separates
geometric travel from jump height.

1. `geometry-screen.json`: 30,000 broad-swing four-bars; the best combined
   near-vertical stroke/fold/reach candidate yielded about 52 mm stroke.
2. `partial-geometry-screen.json`: another 30,000 geometries allowing limited
   connected crank travel. Full rotation is not a user requirement. The best
   folding and recovery-reach candidate yielded about 131 mm stroke.
3. `refined-geometry.json`: 12,000 local samples around promising candidates,
   retaining a knee lever of at least 14 mm and adding a preliminary force
   screen. It found 165 accepted sampled intervals. The selected layout has
   **153.1 mm nearly vertical travel** while preserving fore/aft and above-hip
   reach. These are finite searches, not optimality or impossibility proofs.

An equal-link, internally belted 2:1 knee constraint was also calculated: it
provides about 179 mm vertical travel with 100 mm links, but zero fore/aft wheel
reach relative to the hip. It remains a comparison, not the selected mechanism.

Selected four-bar dimensions (mm): upper 104.229, lower 112.832, tie 98.197,
knee lever 14.501, fixed inner pin (11.613, 14.059), lever phase 2.72761 rad.
The sampled connected branch spans hip −2.8…+1.08 rad; the jump-alignment segment
uses −0.38…+1.03 rad. Axle X stays within 8.5 mm of a +15 mm line in that segment.
The actual complete COM has not yet been aligned with that line.

The force screen uses a **2.2 kg mass allowance**, equal vertical support and
constant acceleration over the whole stroke to an assumed 250 mm COM ballistic
rise. It estimates up to 3.73 Nm hip torque and 209 N tie force, with about
1.55 J released by the spring pair. The spring geometry allocates 65/20 mm seats
from the knee and a 64 mm free pin span for a 50 mm spring and end fittings.
These results omit link inertia/gravity, actual motor torque-speed, pitch,
contact dynamics and landing impacts. They do not demonstrate a 250 mm jump or
qualify any component. A tiny printed tie/lever cannot be assumed adequate just
because the kinematics close.

## Revised interfaces and internal spring

`layout.py` now includes paired **626 (6 ×19 ×6 mm) knee-bearing envelopes**,
a 6 mm steel shaft with local flats, separate axial layers for the steel knee
lever and tie, and an outboard wheel service lid. The lid/frame overlap and
inboard cap interference in the first layout are removed. Bearing dimensions
are nominal allocations; a supplier, fits, retention and ratings remain open.
The guide's steel stem is 6 ×3 mm with 8 mm end eyes. A round bore alone is no
longer the proposed knee torque interface, but the flats still require a
retained, load-qualified connection to the printed shin.

`compare_spring_paths.py` records the earlier strut envelope overlapping the
inner knee bearing at three of 41 sampled poses (up to 3.93 mm³). It caps the
spring at its free length and excludes the new guide blocks from the comparison.
This is a coil-envelope conflict, not a measured helix contact. The new
`spring_cartridge.py` keeps the selected **MISUMI SWF12-50** spring lengthwise
inside the thigh. The same knee lever gains a 14 mm spring crank. A passive
40 mm connecting rod moves a printed spring seat along a steel guide. Guide
supports and the fixed spring seat are integrated into the thigh print. This
adds one small printed slider and one passive steel link per leg, with no
additional actuator. End retention and the actual pivot screws/bushings are
still missing; the spring must remain captive when the moving seat is unloaded.

The kinematic spring check uses 1,201 hip positions and the spring's specified
50 mm free length / 5.5 N/mm rate:

- Maximum compression: **19.65 mm**, within the 20 mm design limit.
- Peak spring force: **108 N**; connecting-rod force: **113 N**.
- Peak transverse slider load: **34.8 N**. Friction cannot be ignored in the
  eventual actuator/energy model.
- Ideal spring-pair energy released through the selected stance: **2.09 J**.
- The earlier constant-acceleration, 2.2 kg load allowance gives about **3.74 Nm
  peak hip torque** and **209 N tie force** with this spring path. These are
  still a preliminary load screen, not a predicted jump.

A simple steel-beam guide screen (E =200 GPa; support centres 0.5 and 11 mm,
side load applied at the moving seat) gives 230 MPa /0.41 mm for a 4 mm guide,
versus **118 MPa /0.17 mm for 5 mm**. The CAD uses 5 mm. These are ideal elastic
calculations, without stress concentrations, wear, bearing clearance, guide
compliance, fatigue or a selected shaft grade; they are not a strength pass.
The 5 mm guide also needs its clearance checked against the spring's 6.5 mm ID
under manufacturing variation and load.

## Earlier linkage-only CAD and clearance evidence

The revised fold measures approximately **194 ×180 ×170 mm**, including the
fixed camera and allocated wheel drives. There are **fourteen connected prints**:
the previous twelve body/link/lid/wheel pieces plus two small spring sliders.
All fit within an A1 Mini bounding envelope. This is not a sliced plate count.

`check_interfaces.py` checks intended bearing seats/journals, the body seam,
and spring end seats with exact CAD intersections. All **39 checks pass with
zero overlapping volume**. It caught and prompted removal of a 1 mm protrusion
on the first slider that intersected the spring. An unloaded spring is allowed
to leave a gap to the moving seat; it is not stretched to bridge that gap.

`check_layout.py` uses 841 independent-leg combinations and a further 401-point
symmetric sweep. It includes conservative spring annuli and filled tire rotation
envelopes, so spring windings and wheel angular phase cannot hide an overlap.
The **1,242 sampled poses pass** for the modeled parts. Intended surface contacts
are excluded only after the exact-CAD check and input hashes match. The original
failed 289-case audit remains archived as `layout-fit-initial.json` from commit
`f5b4503`; `layout-fit.json` is the current result.

This is **not complete-robot fit validation**. The nominal leg drive volume has
shrunk to Ø48 ×14.5 mm once actual wall clearance and the outboard cover are
reserved. It does **not** fit the selected V2806 motor plus reduction, shaft
support and encoder. Hip motors/reductions, the grounded tie-pin support, pivot
hardware, fasteners, spring/shaft retainers, electronics and wiring still need
installation and checking. Those missing pieces must not be treated as fitting
just because the shown parts no longer intersect. `complete_robot_fit_pass`,
`mechanical_fit_pass`, `dynamics_validated` and `hardware_release` remain false.

The 120 ×20 mm dished wheel uses a 160 mm centre track. It is a different part
from the R2 wheel in the existing verified jump. No motion evidence transfers.
The viewer's Cutaway shows the new spring route and slider at each actual leg
pose; the old R2 viewer retains its original spring and programmed recording.

## Cost evidence

`motor-prices.json` records current manufacturer product/variant API prices on
2026-09-08, excluding tax and shipping. Existing X2216 880KV hips remain $24.99
each; V2806 650KV wheels remain $28.99 each. The motor-only four-drive baseline
is therefore $107.96. Two more X2216 motors would add $49.98 **before** drivers,
encoders, transmissions, bearings and mounts. Nothing is purchased.

A flatter V3508 family is listed at $42.99 each, but is only a screening option.
Its 380-labeled winding table also lists Motor Kv 350; that discrepancy needs
resolution before using it for sizing. Propeller-cooled current ratings do not
establish sealed-joint duty. Keep the existing motor pair unless packaging and
loaded torque-speed comparisons justify the extra $28 per pair. A lower ratio
alone can remove needed launch torque.

Sources: [X2216](https://sunnyskyusa.com/products/sunnysky-x2216-v3-brushless-motors-long-shaft-version),
[V2806](https://sunnyskyusa.com/products/sunnysky-v2806-motor),
[V3508](https://sunnyskyusa.com/products/sunnysky-v3508-motor).

## Wheel drivetrain packaging work

`wheel-drive-study.md` records the dimensioned V3508 direct-drive comparison and
the offset V2806 geared-drive search. The direct candidate includes the source
motor's shaft projections, shallow mounting threads, a one-piece tire and
compression limiters. It fails the 180 mm package target in the tested layout
and has substantially greater estimated winding loss at the same crawl torque.
It has **not** replaced the V2 drive selection.

The detailed component study places the existing geared motor 30 mm beside the
wheel axis in the shin's X/Z plane. It now includes stock gear hubs, two flanged
bearings, shaft and torque plate, a metal motor adapter and mounting plate, and
an integrated printed shin/case. Its 120 ×20 mm TPU wheel remains one connected
print. The wheel, structural case and two service covers total four prints per
module; the complete purchase and machining cost remains open.

Inspect it at http://localhost:8765/viewer/v2-wheel.html using Cutaway, exploded
assembly and prescribed gear rotation. [The component notes](geared-wheel/README.md)
record the sources, assembly sequence, nominal collision/rotation/insertion
checks, preliminary loads and remaining printing/strength work. The 205-pose
screen uses a 3 mm inboard leg shift and body narrowing to 66 mm. The module is
now integrated into the assembly described below. It has not been adopted into
a native V2 plant or validated in a jump.

## Previous wheel/linkage integration checkpoint (`5c43860`)

The measurements in this section describe the committed compact assembly before
the requested D435i/body/wiring update. The current `assembly.*` exports have been
regenerated; use the body update above and the matching JSON reports for current
dimensions and checks.

`assembly.py` generates actual CAD for both detailed wheel modules, shifts the
retained leg internals 3 mm inboard and narrows the body laterally by 66/72.
`assembly.step`, `assembly.json` and `assembly-parts.json` were that viewer's
assets; the older `layout.*` files remain the linkage-only source checkpoint.
The spring centre moves with the leg, so the viewer and collision check use the
same 44 mm lateral spring position.

The shown assembly has **16 connected prints and 170 CAD solids**. Motor internal
pieces and each fastener are separate solids; 170 is not a purchase count. The
extra rear motor/sensor cover adds one print per leg compared with the earlier
14-print layout. Printed volume is about 422.8 cm³, down from 437.0 cm³ before
integration. All shown prints fit an A1 Mini bounding envelope, but orientation,
support, actual plates and missing mounting parts remain to be resolved.
The folded bounds remain approximately **194 ×180 ×170 mm**.

`check_assembly.py` passes retained-part mutual clearance and both complete wheel
modules over 841 independent-leg combinations and a 401-pose symmetric sweep.
The module compounds use conservative rotation envelopes externally; their
internal nominal mating and rotation evidence is inherited only after checking
source and asset hashes. No camera geometry is silently excluded. Previously
checked bearing/seat contacts remain valid under their shared translation; the
body seam shares the same affine scale. This remains a finite nominal check of
the modeled assembly, not complete robot fit or a tolerance pass.

`assembly_properties.py` verifies mesh topology and geometric properties before
any mass assignment. Finer body tessellation and removal of four zero-area
camera-pole triangles fix the initial export failures, preserved in
`assembly-properties-before-export-fix.json`. No surfaces are filled to hide a
hole. All 170 current meshes are watertight and consistently wound, with volume
error below 1% relative to exact CAD (body parts below 0.307%). Unit-density
inertias are saved for later material and purchased-component mass assignment.
Complete robot mass is still unknown while hip drives and electronics are missing.

## Hip support and drive sizing

`hip_support.py` and `check_hip_support.py` investigate the fixed end of the
internal tie. Four of five axial bracket planes interfere with the spring,
thigh or tie. A 3 mm metal bracket at Y=54…57 mm clears 405 sampled poses, with
only 0.5 mm nominal clearance. An ordinary inward-facing button-head pivot
hits the spring guide during folding. `hip-tie-anchor-fit.json` retains that
failure; the bracket and fastener are **not** installed in the accepted assembly.
A complete fixed spindle, hip bearing arrangement, smooth retained pivot and
output transmission are still needed. Simply bolting the tie to the rotating
thigh would change the mechanism and is not an acceptable substitute.

`hip_drive_screen.py` adds a prescribed one-dimensional launch sizing check.
It uses the actual linkage/spring path and a 250 mm ballistic COM-rise allowance,
but omits link/gear inertia, contact and body rotation. At the retained X2216
880KV motor's assumed 32 A limit, 12:1 fails this profile; 16:1 requires about
23.8 A nominal and 29.3 A at 20% greater mass. Ratios 20:1 and 24:1 also clear
this limited calculation. No ratio or new hip gearbox is thereby adopted.
An independent work/energy balance includes motor rotor acceleration and checks
the torque calculation; it does not establish a jump or adequate thermal duty.

The [short-shaft motor source](https://sunnyskyusa.com/products/sunnysky-x2216)
and its drawing are archived under `hardware-references/`. The source confirms
the selected short-shaft SKU at $24.99 on 2026-09-08, the 27.7 ×34 mm body,
3.175 mm shaft, three M2 rotor holes on Ø12 and 2.8 mm mounting-thread depths.
This resolves the earlier price record's long-shaft listing without borrowing
the V2806 wheel motor's different rotor mounting pattern. Prices exclude
shipping/tax; sealed-joint duty and driver conventions remain unqualified.

## Remaining work toward the full objective

1. Complete the hip drivetrains, grounded tie-pin supports, spring and shaft
   retention, pivot hardware and fastening. Qualify the integrated wheel drives,
   printed guide supports and positive knee torque connection, with tool access
   and load paths.
2. Verify independent leg motion, spring travel, storage folding and assembly
   sequence with all hardware installed. Derive true CAD masses/inertias.
3. Build a separate free-body native MuJoCo plant with those exact masses,
   collision geometry, spring routing, limits, rotor inertia and electrical
   assumptions. Adapt controllers to this linkage's actual branch; existing
   recovery helpers hardcode old hip and knee ranges and must not be reused
   blindly. Optimize takeoff/tuck/landing and test at both timesteps.
4. Evaluate the full fall-family bank, speed/stop, uneven terrain and dynamic
   one-wheel transition/hold/disturbance rejection. Two-wheel differential
   extension and static COM alignment do not prove single-wheel roll control.
5. Compare independently powered knees only where measured four-motor deficits
   remain. Include the complete extra drive mass, coupling and cost; six planar
   motors alone do not guarantee lateral one-wheel stability.
6. Complete sourced BOM, printable part and plate plan, structural/landing
   calculations, motor/spring identification plan, policy interfaces and sim2real
   validation. Physical material/traction/fatigue tests remain an explicit limit.

The goal is still open. This checkpoint does not meet the full required motion
set or constitute a finished robot design.

To reproduce the integrated assembly and its checks after the earlier linkage
and detailed wheel sources are present:

```sh
.venv/bin/python design/clanky-v2/assembly.py
env OPENBLAS_NUM_THREADS=1 uv run --no-project --python /usr/local/bin/python3.11 \
  --with trimesh --with python-fcl --with rtree python design/clanky-v2/check_assembly.py
env OPENBLAS_NUM_THREADS=1 uv run --no-project --python /usr/local/bin/python3.11 \
  --with trimesh --with rtree python design/clanky-v2/assembly_properties.py
.venv/bin/python design/clanky-v2/hip_drive_screen.py
.venv/bin/python design/clanky-v2/hip_support.py
env OPENBLAS_NUM_THREADS=1 uv run --no-project --python /usr/local/bin/python3.11 \
  --with trimesh --with python-fcl --with rtree python design/clanky-v2/check_hip_support.py
```

## Reproduce the earlier geometry checkpoint

```sh
.venv/bin/python design/clanky-v2/geometry_screen.py
.venv/bin/python design/clanky-v2/partial_geometry_screen.py
.venv/bin/python design/clanky-v2/refine_geometry.py
.venv/bin/python design/clanky-v2/spring_cartridge.py
.venv/bin/python design/clanky-v2/layout.py
.venv/bin/python design/clanky-v2/check_interfaces.py
uv run --no-project --python /usr/local/bin/python3.11 --with trimesh --with python-fcl --with rtree python design/clanky-v2/check_layout.py
```

`tests/test_v2_geometry.py` compares the selected mechanism with the established
independent solver over 1,201 angles, checks closure and branch continuity, and
checks exported folded bounds and explicit unqualified status. Browser checks
cover loading, Fold/Ride, Cutaway and the manual controls. These checks prove
only their stated geometry/viewer scope.

`tests/test_v2_cartridge.py` checks the slider closure, unilateral spring force,
travel limit and force/energy consistency. Four Python geometry/cartridge tests
and five existing JavaScript CAD/replay tests pass. These do not establish the
required dynamic skills or physical durability.

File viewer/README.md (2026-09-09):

# Clanky motion viewer

Open `/` or `/viewer/` when running `python3 design/viewer/serve.py --host 0.0.0.0`.
Both route to `skills.html`, as does the published site's main page. The viewer
starts and loops the **programmed jump** automatically.

The pages also support plain HTTP LAN and Tailscale IP URLs. `sha256.mjs` uses
native Web Crypto on secure origins and a SHA-256 fallback when `crypto.subtle`
is unavailable, including iOS over HTTP. Asset integrity checks stay enabled.
`node --test tests/test_viewer_sha256.mjs` checks padding boundaries, typed-array
offsets and the real CAD asset against Node's independent implementation.

For the latest mechanical design, open `http://localhost:8765/viewer/v2.html`.
The motion and wheel pages link to it directly. V2 now opens the whole robot in
Exterior view with the latest left output joint and body-case overlay, playing
its first **programmed V2 jump experiment**. The motion dropdown also offers
programmed balance and Manual. Cutaway, Packaging and Focus on output joint
expose the internals; Physics shows the compiled native collision shapes.
Manual retains Fold/Crouch/Ride/Extend and both/left/right sliders. View and motion
selection are retained in the URL, for example `v2.html?view=cutaway&motion=manual`.
The earlier body, spring and gear layouts remain under explicit `study=body`,
`study=spring` and `study=drive` links; `study=output` still opens the latest overlay.
The left hip is more detailed than the right. V2 replay poses come from recorded
MuJoCo generalized coordinates through native forward kinematics, without a
viewer ground lift. CAD and collision shapes follow the same transforms. The
nominal jump now clears 264.31/264.25 mm at the two physics timesteps, with a
settled landing over the final two seconds of each eight-second trial. COM rise
is about 195 mm; the leg tuck supplies the additional wheel clearance. Four of
ten sensitivity cases pass; ±20% mass changes and a 9.6 V supply fail landing
and/or height checks. This remains an experimental controller on an unqualified
plant. No learned or arbitrary-fall recovery result is implied. The R2 link
retains its original robot and evidence. The first 81 mm V2 replay is archived
at commit `6d3f645`.

Generate these recordings with `native_viewer_trials.py` and export them with
`export_native_replay.py`, using `.venv-sim/bin/python` under `design/clanky-v2/`.
`native_jump_validation.py deeper-tuck-3` runs the fixed ten-case sensitivity
grid; `native_viewer_trials.py --from-validation` reuses its matching nominal
recordings without retesting them. `native/selected-jump.json` selects the profile.
The viewer checks the recording against current CAD and model hashes. A missing
or stale replay leaves manual CAD inspection available.

The newest actuator study is visible at
`http://localhost:8765/viewer/v2-actuator.html`, linked from V2 and the motion page.
It compares the current stock-gear layout with all 31 solids from the archived
RS05 supplier STEP, at equal millimetre scale. Both / Current / RS05, orbit,
Output face and Side controls inspect the assemblies. The spindle-conflict toggle
highlights the three source solids intersected by the existing 8 mm fixed shaft.
The custom case and detailed output joint are omitted to expose the gear train.
This does not replace the robot's drive or claim an assembled integrated option.
Export its hash-bound supplier mesh with
`.venv/bin/python design/clanky-v2/export_actuator_viewer.py`.

One dropdown contains 14 recordings for the same 2.45 kg, four-motor recovery
revision (`wide_current`): learned balance, driving/turning, height control and
push recovery; programmed jump/landing and nine programmed get-up starts.
Recordings are selected by model hash, so original-design policies cannot appear
as a second candidate. Their archived files remain available for research.

Drag to orbit, scroll to zoom, or select 3D, Side, Front and Fit. Playback controls
include pause, restart, speed, timeline, looping, peak jump and stable finish.
Results and evidence links are collapsed by default. URL parameters `demo` and
`policy` still select matching recordings; absent, unknown and old-model IDs fall
back to the programmed jump.

The same compiled MuJoCo exterior hulls render every motion. This is the
simulation geometry; it does not show internal gears or springs. No new physics
runs in the browser. The learned badge requires a passing report with matching
policy/model identity; programmed assets retain their checksums and diagnostic
classification. Selected get-ups do not qualify recovery from arbitrary falls.

The earlier CAD studies remain in `validation.html`, `internal.html`,
`streamlined.html`, `brushless.html` and the other historical pages. Their pose
sliders and cutaways describe those archived designs. They are not alternative
models in the main motion viewer.

Three.js 0.180.0 and OrbitControls are vendored under `vendor/` with their MIT
license. Runtime assets load from the same server. Verify the motion inventory
and evidence gates with `node --test tests/test_skill_recordings.mjs` and package
Pages with `python3 scripts/build_pages.py` after staging new assets.

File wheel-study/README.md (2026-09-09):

# One-piece TPU wheel: revised 120 mm candidate

Local viewer, with the programmed jump playing by default:

http://localhost:8765/viewer/wheel.html?scene=robot&motion=jump

R2 clears the sampled CAD sweep and completes the programmed jump in native
MuJoCo. Nominal both-wheel ground clearance is **96.6 mm**, compared with
86.0 mm for the original 100 mm wheel plant using the same jump controller.
Corresponding centre-of-mass rises are 64.6 and 55.3 mm. The original plant
and its trained policies remain unchanged.

## Construction

| Item | R2 candidate |
| --- | --- |
| Tire, web and centre | One connected TPU 95A print per wheel |
| Diameter × tread width | 120 × 20 mm |
| Flat print envelope | 120 × 120 × 20 mm; one A1 Mini plate per wheel |
| Estimated TPU mass | 109.5 g each, CAD volume × assumed 1.2 g/cm³ |
| Tire centre track | 206 mm, previously 150 mm |
| Overall tire-to-tire width | 226 mm, previously 180 mm |
| Estimated complete robot mass | 2.292 kg, previously 2.448 kg |
| Actuators, springs and linkage | Existing four-motor arrangement |

The first wheel hit the housing and folded thigh. R2 narrows the tread,
recesses the coupling into the integrated centre, and moves each tire 28 mm
outward. A recessed centre alone cannot solve the thigh collision. This wider
stance increases axle overhang and affects get-up dynamics.

Each wheel uses one [Pololu 2693 8 mm shaft coupling](https://www.pololu.com/product/2693/specs),
three M3 ×8 socket screws and three Ø7 ×0.5 mm M3 washers. The coupling pair is
listed at $14.95 (checked 2026-09-08), the same SKU already used at the hips.
Three alternating holes of its six-hole Ø19.05 mm pattern mount the wheel.
A rear-open tool channel reaches the radial set screws. Two 80 ×8 mm steel
shafts replace the 61 mm shafts; a local 0.5 mm flat sits under each coupling,
away from the bearing seats. Motors, reduction gears and bearings are retained.
There is no separate printed rim.

The coupling CAD follows the [manufacturer drawing](https://www.pololu.com/file/0J1331/pololu-universal-aluminum-mounting-hub-for-8mm-shaft-m3-holes-dimensions.pdf).
Thread detail and radial screw holes are omitted from its simplified mesh;
the assigned 6.7 g coupling mass includes its supplied set screws.

## Verification

`revised/fit-report.json` checks both wheels at 105 hip angles each, from
−2.6 to +2.6 rad. A filled rotation envelope covers every tire angular phase
at each sampled leg pose. No interference was found; the minimum rigid CAD
clearance is **2.33 mm**, at the thigh lid. Mounting parts were also checked
against retained CAD at every fourth leg pose. Intentional shaft seating in
bearings and gear is excluded. This is a finite mesh audit, not proof of
clearance with a deformed TPU tire under load.

MuJoCo 3.10.0 uses the new CAD-derived wheel mass, COM and full inertia tensor,
120 ×20 mm rigid tire cylinders with the actual lateral offsets, and explicit
tire-to-skin contact pairs. Existing electrical motor models, spring limits
and linkage constraints remain active. Physics view shows these collision
shapes; Enclosed and Cutaway show detailed CAD.

| Programmed check | 0.5 ms / 0.25 ms result |
| --- | --- |
| Jump, nominal | Pass / pass; 96.65 / 96.04 mm wheel clearance |
| Jump, 20% heavier | Pass / pass; 94.32 / 94.61 mm |
| Jump, 9.6 V battery | Pass / pass; 78.59 / 78.52 mm |
| Lower and raise | Pass / pass |
| Catch 5° pitch + 0.2 m/s disturbance | Pass / pass |
| Drive 1.6 m and stop | Pass / pass; ~5.7 mm final distance error |
| Turn 90° and hold | Pass / pass; ~2.3° heading error |
| Back get-up, existing timing | Pass / pass |
| Left-side, front-left, back-right get-ups, retuned | Pass / pass |
| Right-side get-up, retuned | Pass / **fail**; remains an attempt |
| Front, inverted, front-right, back-left get-ups | **Fail / fail** |

These are exact-start programmed diagnostics with perfect simulated state
feedback, not learned skills or random-fall recovery. Fallen starts use the
archived orientations and joint states, adjusted vertically for the new
contact envelope. A 64-case search scaled timing and wheel torque; promising
settings were then recorded at both timesteps. Four of nine get-up families
currently pass both checks. Attempts remain labeled in the dropdown. Driving
needed stronger position correction after stopping to remove a ~114 mm
residual error. Jump timing was unchanged.

**Still unqualified:** TPU stiffness/damping, loaded deflection, grip and rolling
resistance, hub creep, bolt pull-through/preload, shaft material and gear
retention, bearing ratings, impact/fatigue strength and sealing. Inspect a
slice and bench-test the hub and loaded wheel before building a pair. No
new-wheel off-road or RL policy qualification follows from these flat-ground
rigid-wheel checks. R2 is not a hardware release.

## Files and reproduction

`revised/` contains `wheel.step`, `wheel.stl`, `wheel.json`, body-frame
`replacements.json`, CAD properties/hashes in `manifest.json`, and the isolated
`plant.xml`, `parameters.json` and `geometry.json`. Motion folders retain the
raw native records and summaries; `timing-search/` retains all 64 search cases.
`replays.json` indexes displayed recordings and requires matching checks at
both timesteps to label a motion passed.

```sh
.venv/bin/python design/wheel-study/revise.py
uv run --no-project --python /usr/local/bin/python3.11 --with trimesh --with python-fcl --with rtree python design/wheel-study/check_revised.py

env PYTHONPATH=src:scripts:design/wheel-study OPENBLAS_NUM_THREADS=1 OMP_NUM_THREADS=1 \
  uv run --no-project --python /usr/local/bin/python3.11 --with mujoco==3.10.0 --with scipy \
  python design/wheel-study/check_motions.py --kinds jump \
  --variants wide_current wide_heavy wide_low_battery \
  --output design/wheel-study/revised/jump-verification
```

Use the same motion prefix for `--kinds height balance drive turn front back
left_side right_side inverted front_left front_right back_left back_right`,
or run `tune_motions.py` for the bounded search. Selected retuning:

```sh
env PYTHONPATH=src:scripts:design/wheel-study OPENBLAS_NUM_THREADS=1 OMP_NUM_THREADS=1 \
  uv run --no-project --python /usr/local/bin/python3.11 --with mujoco==3.10.0 --with scipy \
  python design/wheel-study/check_motions.py --kinds back_right front_left left_side right_side \
  --settings design/wheel-study/revised/timing-search/settings.json \
  --output design/wheel-study/revised/retuned-motion-checks
python3 design/wheel-study/index_replays.py \
  design/wheel-study/revised/initial-motion-checks \
  design/wheel-study/revised/motion-checks \
  design/wheel-study/revised/jump-verification \
  design/wheel-study/revised/turn-verification \
  design/wheel-study/revised/retuned-motion-checks
```

CAD regeneration resets status flags; indexing updates them from the evidence.
The index checks fit/CAD hashes and nominal model identity; the browser checks
CAD, collision geometry and replay hashes before display. The repeated 100 mm
baseline matched the preserved 85.99 mm jump. No viewer publishing is performed.

## Archived R1 study

Parent-directory `tpu-wheel-120x25.*`, `tpu-wheel-140x25.*`, `catalog.json`,
`initial-fit.json` and `spacing-study.json` preserve the unsuccessful initial
concept. Both sizes hit the housing; 120 mm also hit the thigh near the jump
crouch. Their provisional four-hole mount is superseded. `generate.py` still
reproduces R1; `revise.py` produces R2.

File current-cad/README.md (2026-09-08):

# Current Clanky display CAD

The homepage uses these detailed meshes for Enclosed and Cutaway views. Physics
uses the compiled collision hulls in `../programmed-jump/geometry.json`.
Both follow the same recorded body transforms; there is one physical design.

Regenerate from the repository root with the CadQuery environment:

```sh
.venv/bin/python design/concept06/export_viewer_cad.py
node --test tests/test_viewer_cad.mjs tests/test_skill_recordings.mjs
```

The exporter reconstructs the frozen assembly used for the current plant's mass
and contact export. It verifies source checksums and compares all 117 solid
volumes, centers of mass and body assignments against
`docs/results/wide-recovery-cad.json`. This export matches those values exactly.
Meshes are in millimeters in each MuJoCo body's local coordinate frame.
The manifest binds the mesh file to the model and plant fingerprints used by
all fourteen homepage recordings.

Display poses interpolate between recorded body transforms for smooth playback;
telemetry and validation use the unchanged original samples. The camera follows
horizontal travel and keeps its height fixed so the jump is visible in the frame.

Springs are drawn procedurally at the simulated pin coordinates. The coil has a
50 mm free length, with 14 mm allocated to end fittings, and becomes unloaded
when the pins separate beyond 64 mm. Coils and tire tread are illustrative;
end fittings, fasteners, sealing and strength remain unqualified. Rendering
material names are palette categories, not a manufacturing specification.

Manual travel holds the chassis level and uses the CAD's bounded stance angle
range. Its height range therefore differs from the archived balance-pitched
stance heights. These prescribed poses are not dynamics or learned behavior.

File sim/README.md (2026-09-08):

# Simulation and transfer plan

This is the **concept-01 height-only plant**. The [enclosed jumping revision](../jump-upgrade.md) requires a different third actuator, elastic transmission and landing model. The current yoke servo must not be used to claim jumping performance.

`build_model.py` generates `clanky.xml` directly from the CAD parameters. `verify.py` checks the wheel and shock geometry at all 27 corner combinations and runs a ten-second passive dynamics smoke test. `plant.py` approximates wheel torque-speed saturation and lag, and rate-limits the shared yoke command. These are an initial plant, not a trained or validated balance controller.

Run `.venv-sim/bin/python design/sim/verify.py` from the project root. The model is compatible with MuJoCo 3.3.7 and has a `nominal` keyframe. Load that keyframe in a MuJoCo viewer to inspect it; it will fall without a balance controller. Use `Plant.step()` before each physics step when evaluating controllers so they cannot bypass its speed/torque and yoke-speed limits. Raw MJCF motors alone do not model voltage saturation.

## Interface

| Channel | Simulator interface | Hardware expectation |
| --- | --- | --- |
| Left/right wheel action | Signed PWM input to `Plant.step`; torque applied to each wheel joint | Bidirectional bridge, current limit, synchronized command timing |
| Shared height action | Target yoke displacement in metres, relative to middle height | Screw motor with measured position or encoder + homing |
| Body motion | Gyroscope and accelerometer sensors | Calibrated IMU; attitude estimator required |
| Wheel state | Joint angle/speed | Encoder counts, direction and velocity filtering; model motor-side backlash |
| Passive suspension state | Arm joint angle/speed | Two magnetic angle sensors; differentiated/filtered speed |
| Height state | Slide position/speed | Homed screw displacement or direct yoke sensor |
| Training-only values | Root world pose, exact contacts and velocities | Do not expose directly to the deployed policy |

Coordinates: X forward, Y left, Z up. Both wheel joint axes point along +Y. Verify electrical encoder and command signs on the restrained hardware; motor assemblies on opposite sides do not imply equal wiring signs. CAD uses millimetres; MuJoCo uses metres, kilograms, seconds and newtons.

The current two wheel actuators are bounded to 0.6 N·m in the simulator, a **provisional short-duration value**. The simple DC approximation uses manufacturer no-load/stall endpoints. Published current/torque points do not fit a single ideal model consistently, so current and temperature are deliberately not claimed to be simulated. Add identified electrical and thermal dynamics before testing aggressive operation.

Zero PWM in this approximation means zero applied terminal voltage with dynamic braking, rather than an electrically open/coasting motor. Match the bridge's actual zero-command behavior. The common-height position actuator is a force-limited servo approximation; it does not yet simulate the screw's motor current, friction, self-locking or thrust-bearing compliance.

## Identify before training for transfer

1. Weigh chassis, battery, wheel/carrier and yoke groups. Measure the assembled center of mass at low/middle/high height. Estimate inertias from the actual CAD/material distribution or a pendulum test.
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

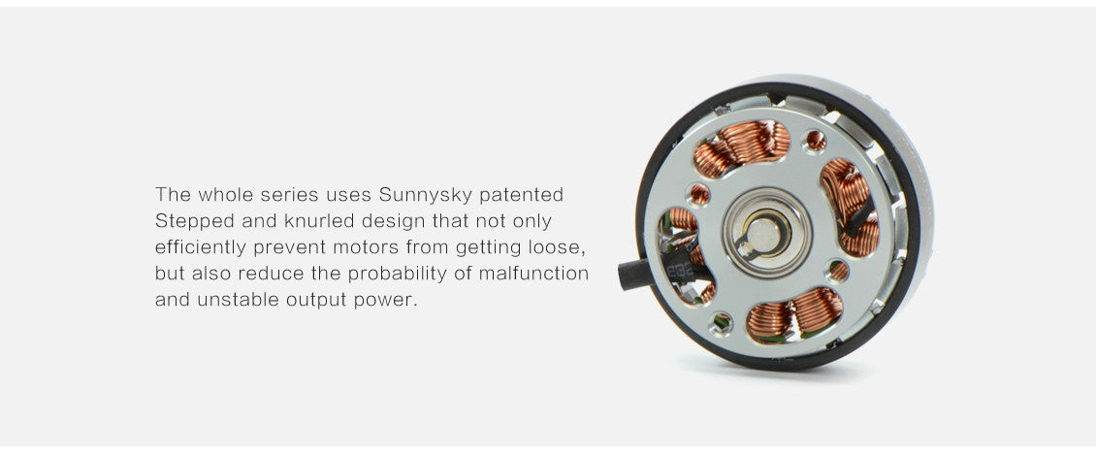
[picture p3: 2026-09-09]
clanky-v2/hardware-references/v2806-sheet-2.jpg

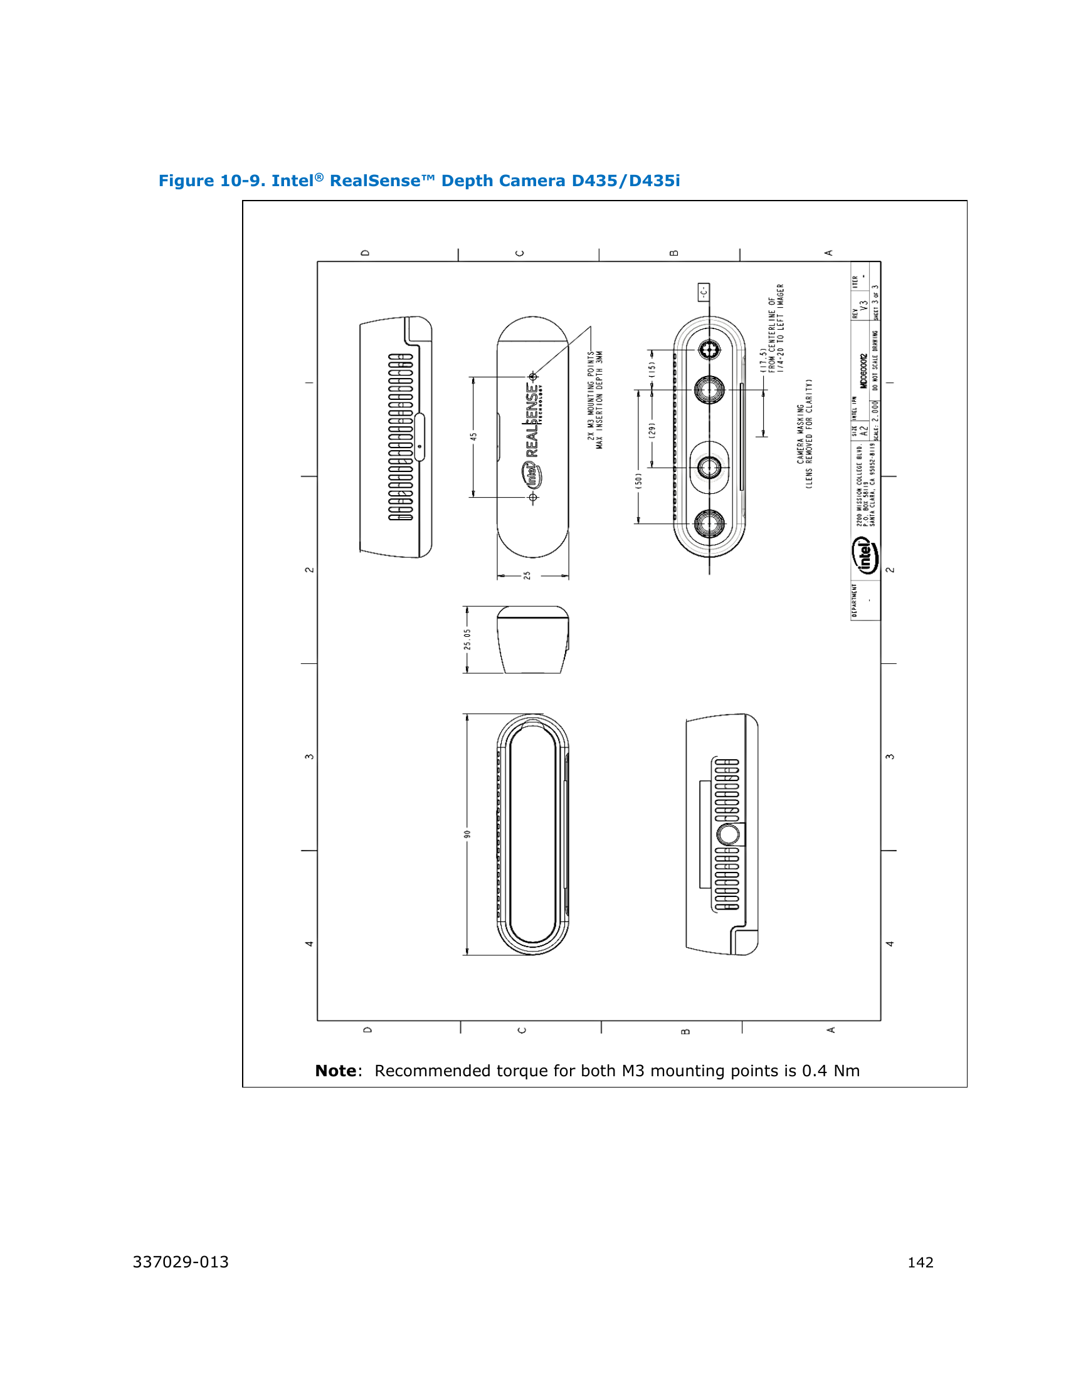
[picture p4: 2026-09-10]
clanky-v2/hardware-references/camera/D435i-mounting-drawing.png

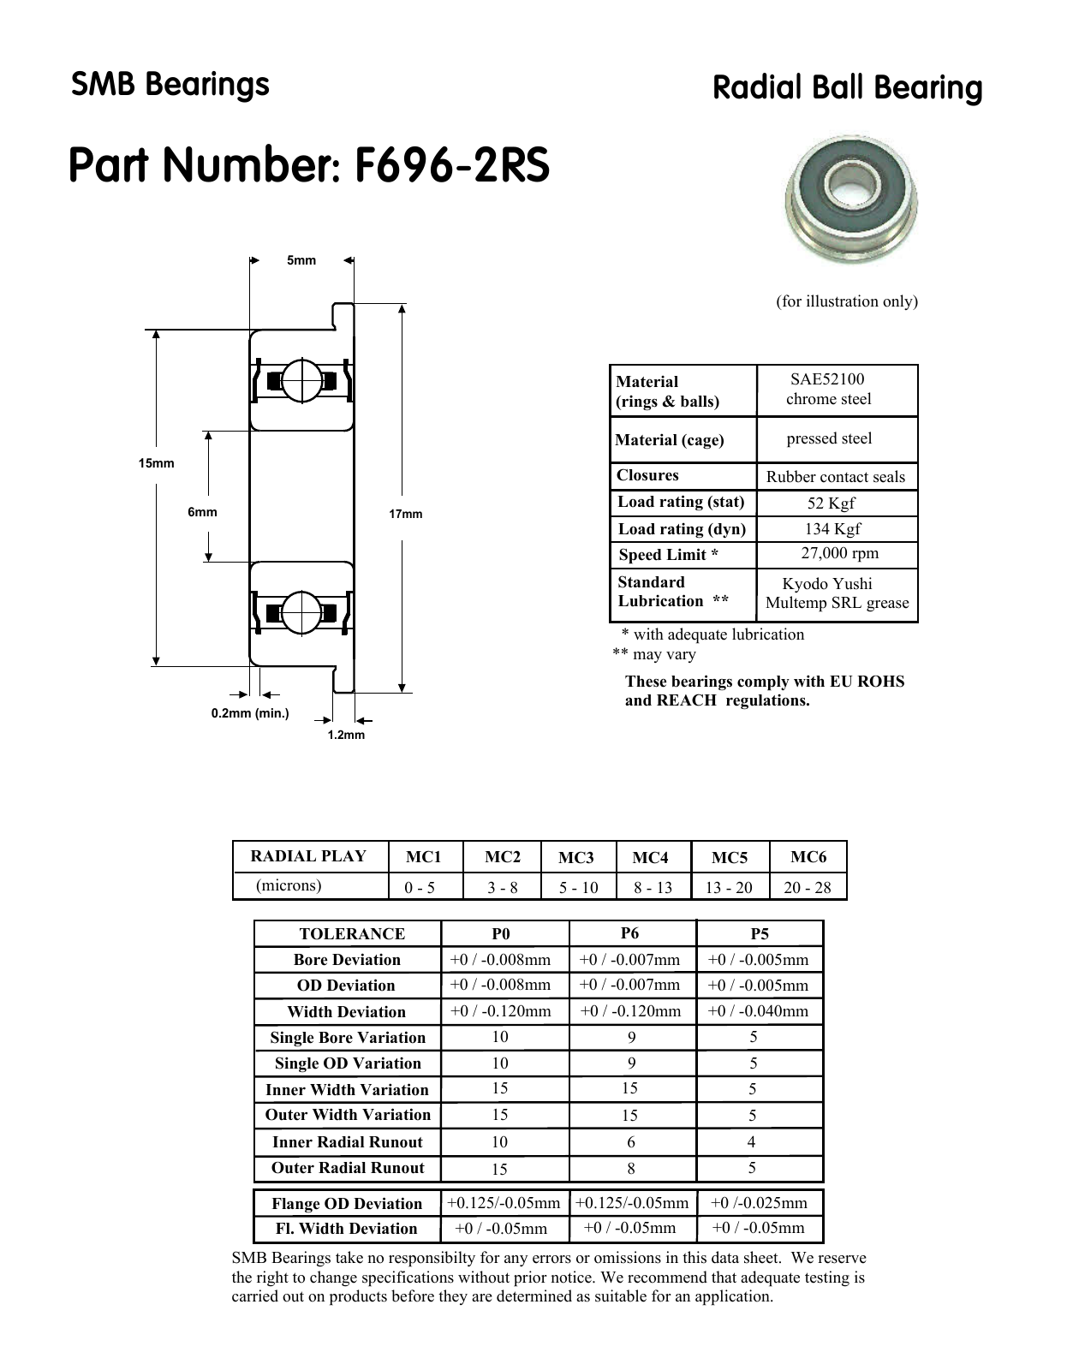
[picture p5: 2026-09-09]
clanky-v2/hardware-references/F696-2RS-drawing.png

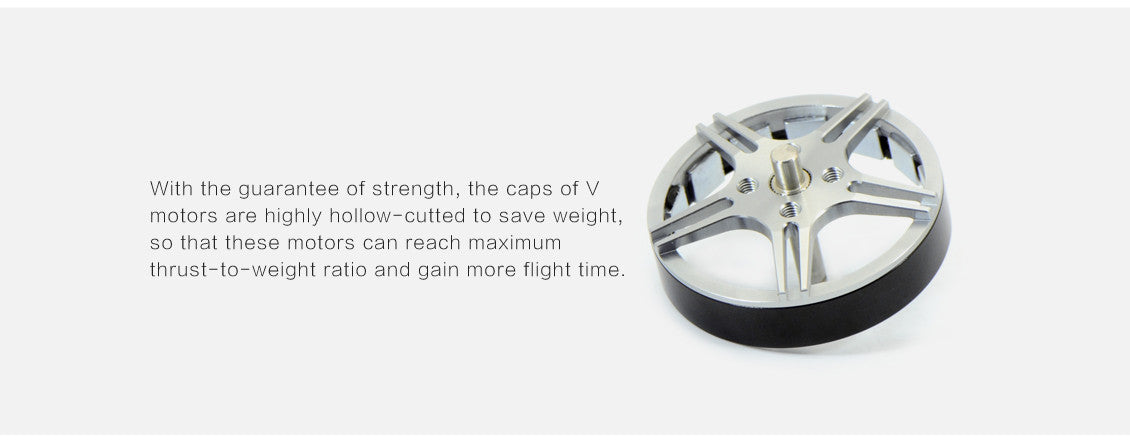
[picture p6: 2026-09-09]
clanky-v2/hardware-references/v2806-sheet-4.jpg

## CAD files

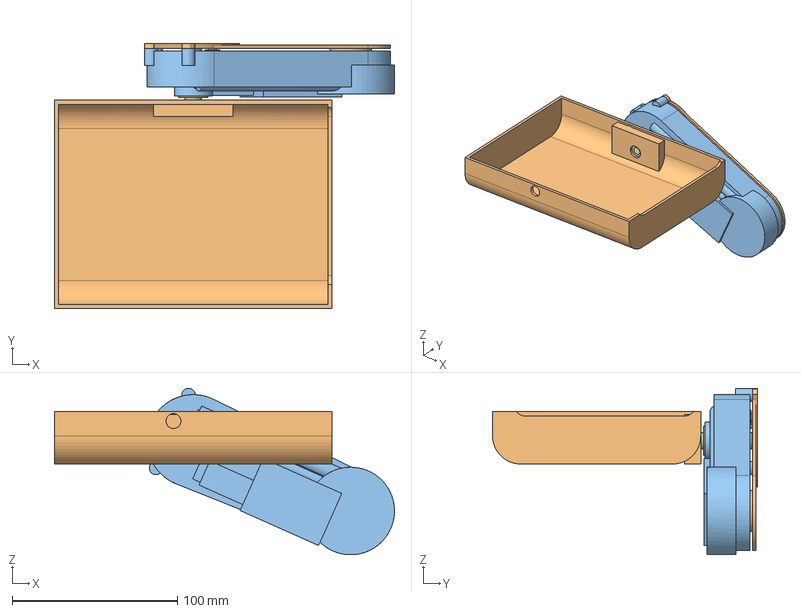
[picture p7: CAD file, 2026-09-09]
clanky-v2/coaxial-spring/study.step
205.7 x 160.3 x 100.7 mm

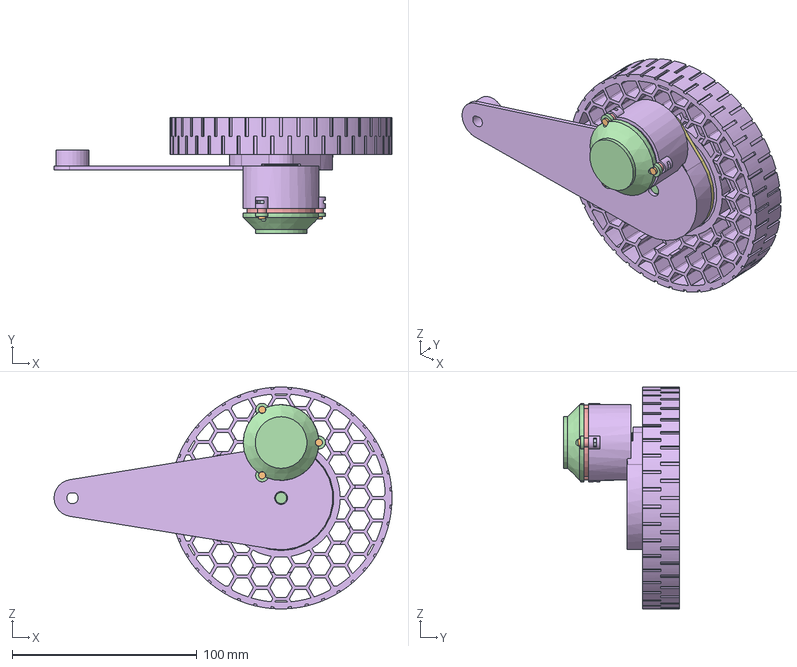
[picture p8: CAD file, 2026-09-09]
clanky-v2/geared-wheel/module.step
182.8 x 62.5 x 120.0 mm

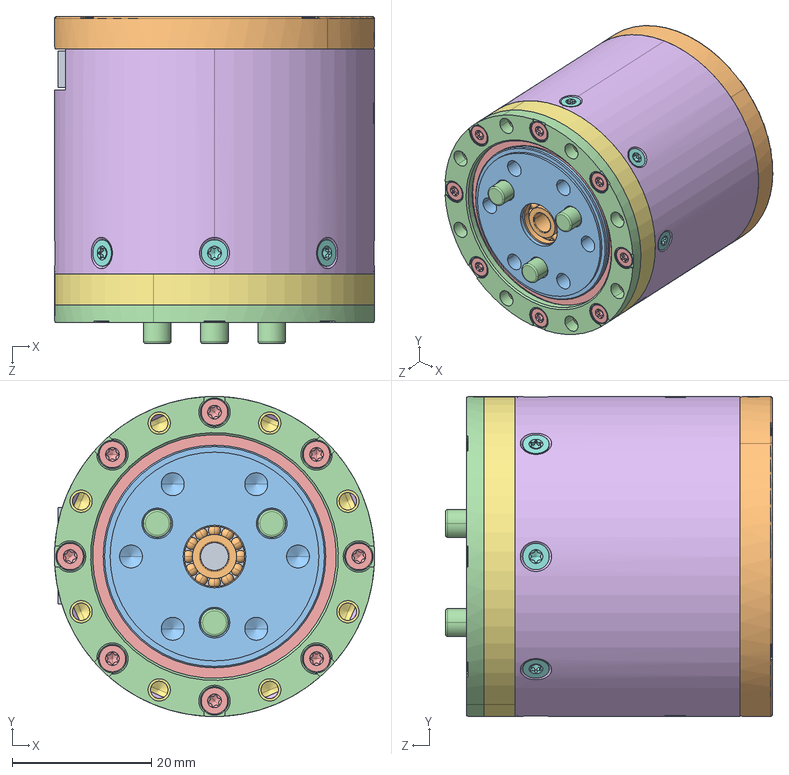
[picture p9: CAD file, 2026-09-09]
clanky-v2/hardware-references/integrated-hips/RS05.STEP
46.0 x 46.0 x 47.0 mm
1_21_121000022__610001_1_1^00MINI-000_ASM_1_ASM_1_ASM_00MINI-_20250103_A0001_ASM_1_AS_ASM_1_1_30_GR-2202_ASM_1_ASM_1_1_30_GR-2202_ASM_FL46BLW10-48V-5N.m-DE(2)_F
0001755650^00MINI-000_ASM_1_ASM_1_ASM_00MINI-_20250103_A0001_ASM_1_AS_ASM_1_1_30_GR-2202_ASM_1_ASM_1_1_30_GR-2202_ASM_FL46BLW10-48V-5N.m-DE(2)_FL46BLW10-48V-5N.
0001755652^00MINI-000_ASM_1_ASM_1_ASM_00MINI-_20250103_A0001_ASM_1_AS_ASM_1_1_30_GR-2202_ASM_1_ASM_1_1_30_GR-2202_ASM_FL46BLW10-48V-5N.m-DE(2)_FL46BLW10-48V-5N.
6706__300001_1_1^00MINI-000_ASM_1_ASM_1_ASM_00MINI-_20250103_A0001_ASM_1_AS_ASM_1_1_30_GR-2202_ASM_1_ASM_1_1_30_GR-2202_ASM_FL46BLW10-48V-5N.m-DE(2)_FL46BLW10-4
0001755652^1_1_30_GR-2202_ASM_1_ASM_1_1_30_GR-2202_ASM_FL46BLW10-48V-5N.m-DE(2)_FL46BLW10-48V-5N.m-DE x 2
1_1_06_EB463-507^FL46BLW10-48V-5N.m-DE(2)_FL46BLW10-48V-5N.m-DE
1_1_02_EB461-502^FL46BLW10-48V-5N.m-DE(2)_FL46BLW10-48V-5N.m-DE
1_2_05_000438^FL46BLW10-48V-5N.m-DE(2)_FL46BLW10-48V-5N.m-DE x 8
1_2_16_001425^FL46BLW10-48V-5N.m-DE(2)_FL46BLW10-48V-5N.m-DE
1_1_06_EB463-509^FL46BLW10-48V-5N.m-DE(2)_FL46BLW10-48V-5N.m-DE
1_2_05_020051^FL46BLW10-48V-5N.m-DE(2)_FL46BLW10-48V-5N.m-DE x 3
1_2_05_000608^FL46BLW10-48V-5N.m-DE(2)_FL46BLW10-48V-5N.m-DE x 4
1_1_31_EB463-510^FL46BLW10-48V-5N.m-DE(2)_FL46BLW10-48V-5N.m-DE
1_2_05_000555^FL46BLW10-48V-5N.m-DE(2)_FL46BLW10-48V-5N.m-DE x 8

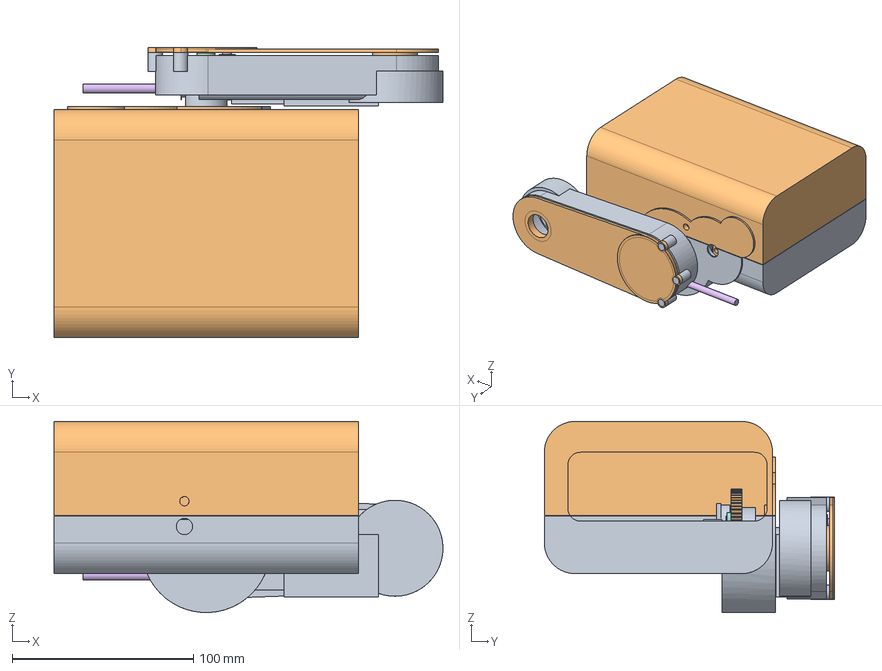
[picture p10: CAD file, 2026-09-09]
clanky-v2/hip-output/parts-local.step
214.7 x 160.3 x 105.5 mm

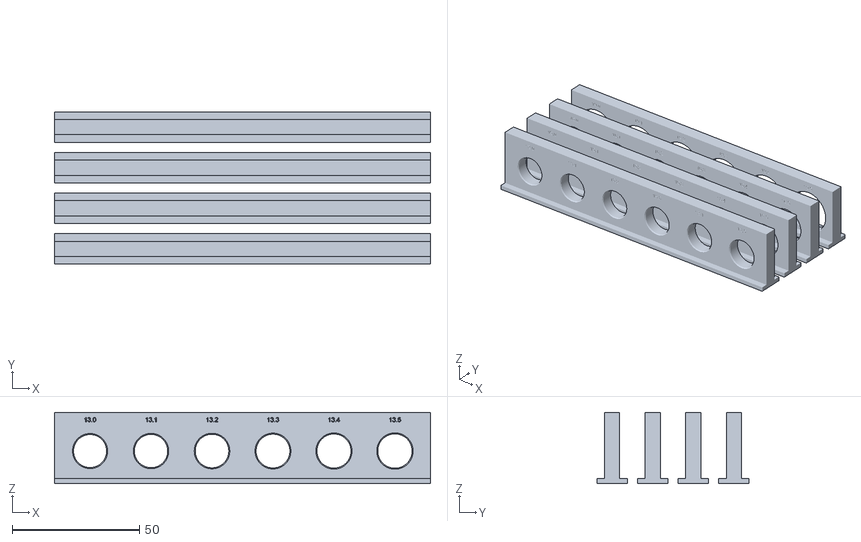
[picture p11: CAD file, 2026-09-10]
clanky-v2/print-fit/horizontal-bearing-plate.stl
148.0 x 60.0 x 28.0

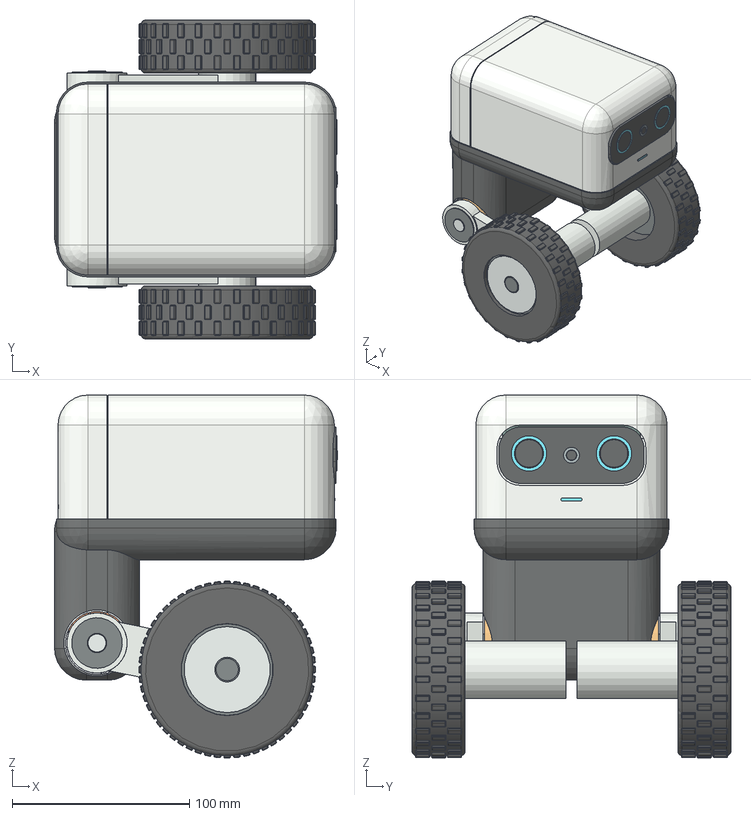
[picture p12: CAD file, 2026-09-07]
output/concept02/beni_enclosed_normal.step
159.8 x 180.0 x 204.9 mm
front_structural_shell
rear_service_shell
lower_impact_wrap
fixed_sensor_visor
eye_ring_-24
eye_lens_-24
eye_ring_24
eye_lens_24
camera_bezel
camera_lens
status_light
jump_drive_reservation
shared_drive_shaft
battery_reservation
control_electronics_reservation
left_covered_arm
left_elastic_coupling_reservation
left_pivot_trim
left_pivot_cap
left_wheel_motor_reservation
left_wheel_shaft
left_tire
left_rim
left_wheel_face
left_hub_center
right_covered_arm
right_elastic_coupling_reservation
right_pivot_trim
right_pivot_cap
right_wheel_motor_reservation
right_wheel_shaft
right_tire
right_rim
right_wheel_face
right_hub_center

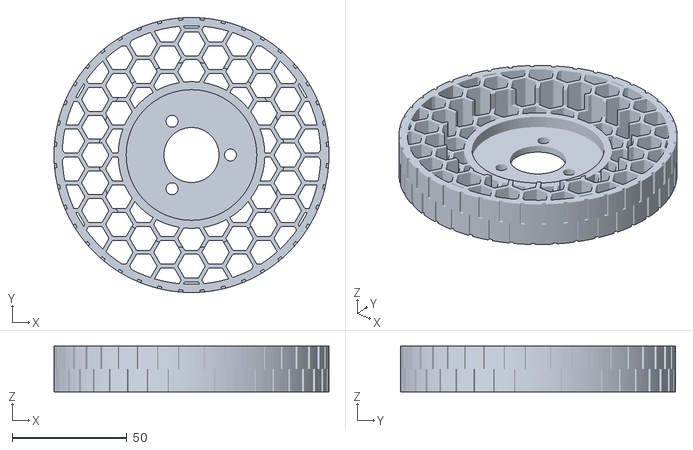
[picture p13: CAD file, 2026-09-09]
clanky-v2/geared-wheel/wheel.stl
120.0 x 120.0 x 20.0

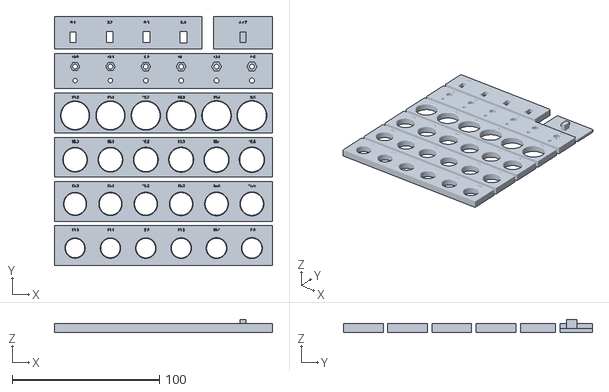
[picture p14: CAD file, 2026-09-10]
clanky-v2/print-fit/rigid-fit-plate.stl
148.0 x 169.0 x 8.50

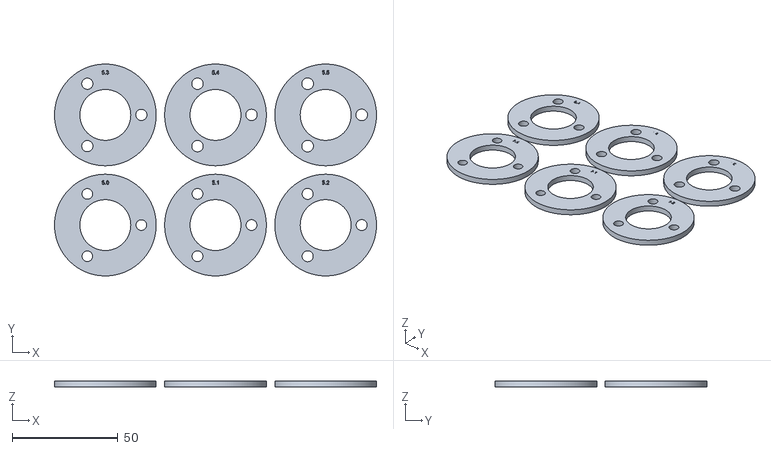
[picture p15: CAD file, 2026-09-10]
clanky-v2/print-fit/TPU-hub-fit-plate.stl
152.0 x 100.0 x 3.00

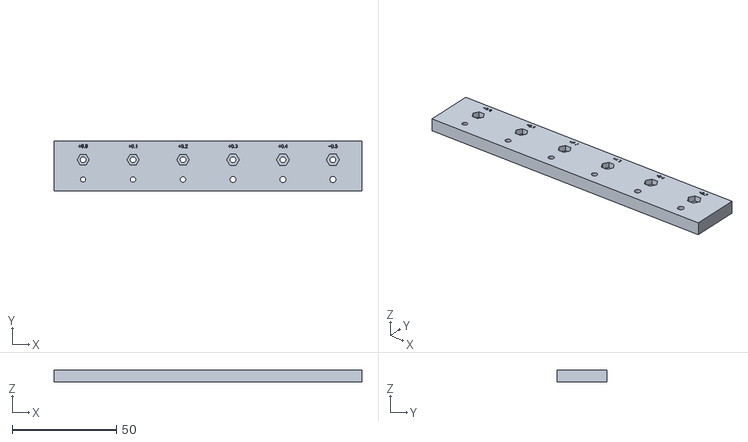
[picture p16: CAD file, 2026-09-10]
clanky-v2/print-fit/M2p5-fasteners.stl
148.0 x 24.0 x 6.00

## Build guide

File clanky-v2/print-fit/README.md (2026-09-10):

# Print fits and tolerances

The current CAD has nominal assembly gaps, **not a calibrated A1 Mini print
profile**. Do not print the full robot expecting every bearing, gear and joint
to fit. The small samples below are ready for slicing and physical fit testing;
their meshes and bed bounds are checked separately. No hardware fit is certified.

For example, the new Ø13.02 mm housing around a Ø13 mm bearing has only 0.02 mm
total diameter clearance (0.01 mm per side). The hip and wheel seats use similarly
small nominal gaps; the knee seats are nominal Ø19 against Ø19 bearings. These
are unfinished fit targets, not a claim of 0.01 mm printer accuracy.

Printer compensation and assembly clearance serve different purposes:

- **Assembly clearance** is the desired space between finished parts.
- **Print compensation** corrects the measured difference between CAD and a
  particular filament, orientation and slicer profile. It can differ between
  holes and outside contours. It must not be applied to purchased metal parts.
- **Manufacturing tolerance** is the allowed variation around the finished
  dimension. A nominal collision-free CAD model does not establish that range.

Prusa's [design guidance](https://help.prusa3d.com/article/modeling-with-3d-printing-in-mind_164135)
likewise recommends clearance and iterative testing because material and print
settings affect fit. Its printer accuracy statements are not an A1 Mini spec.
The A1 Mini's [180 × 180 × 180 mm build volume](https://us.store.bambulab.com/products/a1-mini)
is an envelope, not a dimensional accuracy guarantee.

## Fit samples

All dimensions below and all labels on the samples are **CAD dimensions in mm**.
Rigid and TPU materials require separate prints. These optional calibration
plates are not additional robot components or a final robot plate count.

| File | Features | Use |
|---|---|---|
| `rigid-fit-plate.stl` | Ø13/15/16/19 bearing holes, each +0.0..+0.5 in diameter; M3 holes/nut pockets; 4 × 7 tab and slots | Start here with the intended rigid filament. Seven separate connected samples, arranged within 148 × 169 mm. |
| `horizontal-bearing-plate.stl` | Same four bearing ladders with horizontal hole axes and integral feet | Compare against vertical holes when choosing body/thigh orientation. Match final support settings. |
| `M2p5-fasteners.stl` | Ø2.5..3.0 holes and 5.0..5.5 AF pockets | Pi screws and captive nuts. |
| `TPU-hub-fit-plate.stl` | Six representative 3 mm hub webs; three Ø5.0..5.5 sleeve holes on Ø34 PCD | Fit the Ø5 compression limiters in the actual wheel TPU. Does not test full-wheel stiffness. |

The bearing strips read Ø13, Ø15, Ø16, Ø19 from front to back in the arranged
plate, with diameters increasing left to right. The fastener strip's front row
contains screw holes, its back row nut pockets: labels +0.0..+0.5 add to Ø3 and
5.5 AF respectively (or Ø2.5 and 5 AF in the separate Pi sample). Nut pockets
have a small through-hole so a seated nut can be pushed out. Tab labels are
clearance **per side**, not total slot enlargement. The key is printed separately
on the same plate. Bearing mouths have 0.4 mm lead-ins; measure the straight land.

1. Use the final nozzle, filament, layer height, wall count and slicer settings.
   Keep scale at 100%. Record any existing hole/contour or elephant-foot
   compensation; do not unknowingly compensate in both CAD and the slicer.
2. Print only the relevant samples first. All layouts leave room for a 5 mm brim
   within 180 mm. Inspect the sliced preview, especially horizontal bore supports.
3. After cooling and cleaning supports, measure in two directions and at several
   depths. Repeat critical samples at least three times; record range as well as
   mean. Record actual bearing/sleeve/nut dimensions too. Calipers alone do not
   establish a 0.01 mm bearing fit; use suitable gauges or a measured trial assembly.
4. Check gentle insertion, rotation where required, and removal. Never force a
   bearing by pressing through its balls. A coupon fitting by hand does not qualify
   retention: a loaded bearing must not creep/spin in the housing or lose alignment.
5. Record results in a **copy** of `calibration.template.json`, with material and
   orientation. Positive bore compensation means enlarging CAD by that amount
   in **diameter**, not radius. For example, a Ø13.20 coupon measuring Ø13.00
   indicates about +0.20 correction for a desired Ø13.00 finished hole in that
   tested process. Choose the actual finished fit separately.
6. Apply only measured, interface-specific corrections to a new CAD revision;
   recheck remaining wall thickness, coaxiality, gear centers and full motion.
   Fit a complete housing before committing to a full robot print.

There is intentionally no universal +0.2 mm correction enabled. If a reliable
bearing fit cannot be obtained directly, provide controlled finishing allowance
and finish the coaxial seats together, or revise their retention/support. Do not
freehand enlarge each bearing independently: the gear axes must remain aligned.
Metal shafts, D-bores, bearing spacers and high-speed adapters require their own
specified machining fits; they are not rescued by changing printer settings.

## Stacks that still need measured limits

`audit.json` records ten present nominal interfaces and five **illustrative**
worst-case calculations. The error values are assumptions for sensitivity,
not measured printer performance or supplier tolerances. For example, two
faces each displaced by 0.15 mm can consume a nominal 0.2 mm tab gap. The
rotor screw's nominal 0.15 mm insertion margin can also disappear with screw
length and countersink variation; actual hardware/seat measurements are required.

Gearbox stack checks must include bearing widths, shaft shoulders, circlip
position within its groove, shim thicknesses and housing datums. Summing the two
visible clip gaps alone does not establish available shaft end float. Bearing
retention, selected running clearance and gear backlash remain unqualified.
Likewise, spring piston running clearance must account for both printed surfaces,
heat, wear and dirt. Enclosure seams need a complete-body warp check.

The one-piece 120 mm TPU wheel remains unchanged. Its metal sleeves limit clamp
compression; coupon fit does not prove wheel torque transfer, creep resistance,
jump strength or service life. Those need separate full-wheel tests.

Rebuild with `.venv/bin/python design/clanky-v2/print_fit_coupons.py` and
`.venv-sim/bin/python design/clanky-v2/print_fit_audit.py`. No robot geometry is
changed by these scripts, and the earlier simulation passes remain tied to their
original CAD. `hardware_release` stays false.

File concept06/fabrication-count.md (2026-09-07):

# Enclosed concept 06: purchasing and print-count estimate

There are 18 exported printed parts: 16 rigid parts and two TPU panels. A bounding-box layout fits them on six A1 mini plates, assuming one rigid filament/color. Budget seven or eight print jobs until orientations, supports, brims and material choices are sliced. This is a packing estimate, not a manufacturing release or a proven minimum.

## Purchased components

Allow roughly 40–45 main purchased components or assemblies, plus screws, inserts, washers, clips, wiring and connectors. This is a planning allowance, not a complete shopping list. Assemblies such as motors and encoder kits count once; their internal pieces are not counted separately.

| Group | Planning quantity | Basis |
|---|---:|---|
| Motors | 4 | Two SunnySky hip motors and two Waveshare wheel motors; selected |
| Compression springs | 2 | SWF12-50; selected |
| Tires | 2 | Nominal 100 mm; SKU unselected |
| Metal pinions | 4 | Two per hip; interfaces and procurement unfinished |
| Hip and intermediate shafts | 4 | Two hip shafts plus two intermediate shafts; retention unfinished |
| Linkage pins | 6 | Knee, coupler/guide and fixed guide pivot per side |
| Bearings | Approximately 8 | Four modeled hip bearings plus allowance for two supports per intermediate shaft; support design unfinished |
| Spring-guide/retainer assemblies | 2 | Hardware and detailed part count unfinished |
| Rotor encoder kits, including magnets | 2 | Packaging allocations; selection unfinished |
| Hip FOC drivers | 2 | One per hip; qualification and packaging unfinished |
| Dual wheel-driver board | 1 | Assumes one dual-channel board; unselected |
| Controller and IMU | 2 | Counted separately; could be combined |
| Battery and DC regulator | 2 | One each; unselected |
| **Planning subtotal** | **Approximately 41** | Excludes fastening stock, wiring, connectors, switches/fuses, optional optics/lighting and a charger |

Only the four motors and two springs currently have selected purchasing models. The viewer's electronics blocks and visor/light allocations are not a finished electronics BOM. Additional bearing, bushing, cooling or retention requirements could raise this allowance.

## Six-plate packing estimate

The layout uses a 170 × 170 mm working area inside the 180 × 180 mm plate, with at least 4 mm between rectangular part envelopes. Parts whose thickness runs along CAD Y are laid flat for the estimate. Support suitability, strength-oriented printing and brim footprints have not been qualified.

| Plate | Parts | Count |
|---|---|---:|
| 1 — rigid | Upper body shell, both wheel-motor service lids | 3 |
| 2 — rigid | Lower body tray, both 48-tooth gears | 3 |
| 3 — rigid | Both lower-leg/motor housings, one guide link | 3 |
| 4 — rigid | One thigh housing, both wheel rims, other guide link | 4 |
| 5 — rigid | Other thigh housing, both 60-tooth gears | 3 |
| 6 — TPU | Both compact spring-pocket service panels | 2 |
| **Total** | **Five rigid plates and one TPU plate** | **18** |

The slimmer thighs reduce the TPU panels enough to put both on one plate; the previous broad version required two TPU plates in this layout. The printed-part count stays at 18.

The largest individual exported axis is 169.54 mm. The [machine-readable layout](output/exterior/plate-layout-estimate.json) records orientations and placements; coordinates start at the corner of the 170 mm working area, so offset them by 5 mm on the actual plate. Different rigid materials/colors, large brims or changed orientations may require additional plates. No print-time estimate has been made without slicing.

Regenerate and check the envelope plan with `python3 design/concept06/pack_exterior.py`. It checks every part, all working-area bounds and at least 4 mm separation. It does not choose or validate slicer supports.

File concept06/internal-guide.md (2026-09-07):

# Can the passive knee guide go inside the thigh?

**Superseded preliminary study.** The whole-guide clearance check later found
that this first compact geometry intersects the hip shaft. See
`internal-knee.md` and `/viewer/knee.html` for the revised angled-lever proposal
and the additional clearance/load screening.

The reference `ref/IMG_3974.jpeg` shows an internal lever. The adjoining teardown
images `IMG_3970.jpeg` and `IMG_3973.jpeg` describe a second brushless motor
powering the knee. They support an internal knee transmission, but do not
establish that Beni uses our passive four-bar mechanism. The exact transmission
and actuator count need a complete diagram to confirm.

Our guide is a structural constraint: it links a fixed body pivot to the short
lever behind the knee. Deleting it would leave the knee uncontrolled. Moving
the existing 83.5 mm guide sideways into the thigh does not conceal its side
profile: its fixed body pivot sits about 50.4 mm from the hip centre.

## A compact four-motor alternative

`internal-guide-study.py` evaluates a smaller four-bar using the same 64.48 mm
thigh crank and 119.12 mm lower leg. The fixed pivot moves to (6.81, 13.50) mm
relative to the hip; the guide becomes 70.19 mm and the knee lever 8.47 mm.
No extra motor or moving link is needed in this planar arrangement.

An 8 mm wide straight guide fits within the existing convex thigh side profile
throughout all 101 sampled poses. Its endpoint discs have 3.88 mm clearance
inside the hip outline and 2.53 mm inside the knee outline. Convexity establishes
the intervening bar's planar fit. This does not establish clearance to the
spring, hip shaft, bearings or enclosure in the lateral direction.

The tradeoffs are substantial:

- Geometric vertical travel changes from 99.81 to 115.16 mm. Wheel position
  differs by up to 19.56 mm at the same hip angle; existing CAD poses and control
  gains cannot be reused without updating the model.
- For the same applied knee torque, calculated guide tension/compression rises
  by as much as 4.34 times. The smallest effective knee moment arm is 3.79 mm.
  Thin printed links and closely spaced knee pins cannot be assumed adequate.
- With existing spring-seat offsets, the minimum seat distance is 27.49 mm:
  22.51 mm compression of the 50 mm spring. That is below the prior 25 mm catalog
  maximum but exceeds our conservative 20 mm design limit. Stops, geometry or
  spring attachment must change before using the entire travel range.

This is a viable direction for a detailed mechanism study, not a replacement
assembly. The viewer still has the original guide and anchors. Before replacing
them, size the knee bell crank and bearings for landing loads, arrange separate
lateral planes for spring and guide, add suitable stops, and rerun CAD collision
checks and MuJoCo with the changed geometry.

Run: `.venv-sim/bin/python design/concept06/internal-guide-study.py`.
Results: `output/internal-guide/feasibility.json`.

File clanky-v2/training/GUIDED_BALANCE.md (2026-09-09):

# Guided balance on the 120 mm robot

This experiment learns balance from the existing programmed controller, then
runs the learned actor alone. It retains the current native CAD, four motors,
springs, 120 mm wheels, electrical limits and linkage guards. It is a foundation
for recovery training, not a demonstration of getting up from a fall.

## Findings

The final learned policy passes **16/16 fresh starting poses at both 0.25 and
0.125 ms**, plus the earlier failed-pose regression at both timesteps:
**34/34 eight-second rollouts**. All finish with over seven seconds of
continuous stable standing. Evaluation uses the learned actor alone at 100 Hz.
The bounded balance experiment is finished. The subsequent
[back get-up experiment](RECOVERY_SHOOTING.md) uses this actor as its endpoint;
reliable full fall recovery remains under development.

The first policy passed **15/16 new starting poses at both 0.25 and 0.125 ms**
(30/32 rollouts). The remaining tilted pose causes an overshoot and fall at both
timesteps. The programmed teacher passes that exact pose at both timesteps.
This identifies an imitation/generalization error for that tested start;
it does not establish the mechanism's full recovery envelope.

One DAgger correction collected states visited by the student on 32 further
training starts (all 32 completed successfully). Only the student commanded the
motors during those rollouts; the teacher supplied labels for supervised
learning. The combined dataset contains 51,200 samples. Original validation
episodes were kept byte-identical and separate. The final evaluation uses
fresh seeds 75000–75015 at both timesteps, plus seed 73015 as the explicitly
identified old failed-pose regression. No further correction loop is running.

## Control rate and coordinates

The copied continuous-time controller settles the tested nominal and perturbed
starts at 500 Hz and 100 Hz. At 50 Hz it oscillates without settling. The guided
actor therefore runs at **100 Hz**, while hip PD still runs at 500 Hz and the
original native motor/guide updates run at every physics step. `GuidedEnv`
keeps the episode duration at eight seconds (800 policy steps). The earlier
50 Hz recovery experiments remain archived with their exact original code.
Future PPO fine-tuning must explicitly use this 100 Hz adapter; loading the
learned weights into the historical 50 Hz worker would change the controller.

The first two new teacher-adapter checks are superseded because the adapter
rotated a local `mjOBJ_BODY` angular velocity using the regular body frame.
MuJoCo uses the principal-inertia frame for that API object type. The corrected
teacher queries world-frame velocity directly, like the original controller.
See [MuJoCo's spatial-frame implementation](https://github.com/google-deepmind/mujoco/blob/main/src/engine/engine_core_util.c).
The regression check verifies world/IMU agreement over 32 randomized states.

The historical native environment's `velocity` feature, and earlier recordings
named `velocity_body`, express velocity at the chassis COM in its inertia axes.
Their speed/settling norms and rewards are rotation-invariant; those gates are
not changed by this correction. The old RL actor did not consume these
privileged velocity components. New guidance recordings name them
`velocity_inertial` explicitly.

## Learning and evaluation

The teacher successfully completes 32 demonstrations, yielding 25,600 aligned
pre-action observations and target actions. Twenty-four whole episodes are
training data and eight are validation data. Transient rows receive more
sampling weight than quiet standing. A 128/128/64 MLP is fit with 2,000 bounded
supervised optimizer updates; this is behavior cloning, not a new PPO result.

The policy uses gyro, projected gravity, hip positions/velocities and wheel
velocities. Acceleration, previous actions and constant commands have zero
input weights; the exported actor retains the same 25-input contract. It never
receives teacher COM, world position, contact state or labels during evaluation.
The NumPy export is compared against the actual normalized PyTorch actor.

Every independent rollout starts from a new reset and then advances only via
the four bounded motor commands. Passing requires all eight seconds without a
plant rejection and continuous stable standing throughout the final two seconds:
both tires grounded, body clear, COM lean and roll within 5°, linear speed below
0.1 m/s, angular speed below 0.2 rad/s and hips within 0.08 rad of ride pose.
The teacher is not constructed in learned-policy evaluation.

Artifacts live under `evidence/balance-teacher-*`, `balance-demonstrations-*`
and `balance-clone-*`; `checks/guidance.json` verifies velocity frames and the
100 Hz/four-kHz/eight-second timing contract. Each run includes source hashes
and snapshots. The first two failed teacher checks are retained as adapter
diagnostics and must not be used as evidence against the hardware.

The final checkpoint and all 34 independent recordings are in
[`evidence/balance-clone-02/`](evidence/balance-clone-02/), with the result table
in [`evaluation/summary.json`](evidence/balance-clone-02/evaluation/summary.json).
The local V2 viewer offers **Learned balance · tilted start**, an actual native
rollout from fresh seed 75008. Its exported body transforms come directly from
recorded MuJoCo positions and velocities, with source and CAD identity checks.
The programmed jump remains the default. Nothing is pushed or deployed.

`checks/guided-evidence.json` independently audits all 34 recordings, dataset
and checkpoint hashes, unchanged validation episodes, recorded current ceilings,
sampled linkage closure/branch/COM and the sampled final two-second gates.
Continuous physics-step rejection and stability still rely on the hashed
environment/evaluator; the audit does not rerun all dynamics.

These are nominal flat-floor tests with ideal IMU orientation and encoder
signals. Parameter uncertainty, observation delay/noise, actuator identification,
terrain, full fallen poses, self-contact, TPU deformation and hardware tests
remain required. No self-righting success or physical qualification is claimed.

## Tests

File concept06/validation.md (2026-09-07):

# Current-assembly validation: hardware release fails

[Open the current MuJoCo jump](http://127.0.0.1:8765/viewer/validation.html)
or [use the LAN viewer](http://192.168.86.226:8765/viewer/validation.html).
The animation now follows the internal-knee plant's recorded dynamics. It is
not the earlier exposed-linkage jump dressed in the new exterior.

The design can jump and recover in the nominal rigid-body simulation, but it
**does not pass validation for a powered physical prototype**. The review found
missing positive torque connections, an undersized carrier, inadequate margin
in the printed hip gearing, a delayed-control overtravel failure and unfinished
seals. No hardware tests have been performed. Those are failures or open release
requirements, not qualifications supplied by a successful animation.

## What was actually tested

The plant uses the current 15.16 mm angled knee levers, 65.59 mm passive guides,
independent closed linkages, SWF12-50 spring geometry and 5:1 V2806 wheel drives.
CAD solids supply volume, center of mass and inertia, with explicit density and
bought-part mass assumptions. Rotating output gears and shafts are assigned to
their physical moving bodies. Rotor and intermediate spin use additional
reflected armature approximations; rotor gyroscopic coupling is not identified.

Ground contacts use convex hulls of the actual exterior meshes and cylindrical
tires. They capture the outside silhouette against a flat plane, but do not model
internal self-contact, print deflection, tire carcass compliance or detailed
interaction with irregular terrain. Springs are force-producing tendons, and
all four motor torques are limited by current and voltage. The current-loop lag
is an assumption, not a measured winding/FOC model. The V2806 model starts from
the manufacturer's 650 KV, 227 mΩ and 0.4 A no-load data. Its propeller-cooled
rating does not establish enclosed duty. [SunnySky specifications](https://sunnyskyusa.com/products/sunnysky-v2806-motor).

The mass estimate is **2.391 kg**, versus the old 2.10 kg assumption. This includes
638 g of fully dense printed CAD, solid tire envelopes at 181 g each, the solid
steel wheel-gear allocations at 125 g each, and explicit battery/electronics/
missing-hardware allowances. It is not a sliced or weighed assembly. The heavy
wheel gear and tire allocations are significant opportunities for later mass
reduction; substituting a lighter actual part requires updating the model.
[Mass and inertia breakdown](output/internal-validation/mass-properties.json).

Independent checks cover 121 left/right pose pairs. Wheel position, spring length
and loop closure agree with analytical geometry to numerical precision. Reloading
80 recorded states reproduces the exported body positions and spring compression.
A fit to free-flight COM motion gives −9.812 m/s² vertical acceleration with
0.025 mm maximum fit residual. Halving the simulation timestep changes nominal
jump clearance by 1.23 mm and peak guide load by about 1.5%.
[Plant checks](output/internal-validation/plant-verification.json),
[replay checks](output/internal-validation/replay-verification.json).

## Dynamics results

| Test | Result |
|---|---|
| Nominal jump, current assembly | **121.8 mm** clearance under both wheels; **83.0 mm** COM rise; 278 ms airborne |
| Nominal landing/recovery | Both wheels regain contact, no body-ground contact, spring compression 16.38 mm, final speed −0.030 m/s |
| Settled body orientation | **−8.65° pitch**; COM lean only 0.11°. It balances, but does not meet the retained ±5° body-level criterion |
| Main campaign | **20/21** pass the dynamics criteria excluding body level; **all 21 fail full acceptance** because of body level |
| 5 ms delayed/noisy estimated state | **Fails travel limit:** hip reaches 1.591 rad; checked CAD range ends at 1.50 rad |
| Combined adverse case | 76.7 mm jump; passes those dynamics criteria, still fails body level |
| 250 mm drop with 5° initial roll | Rigid-body recovery passes excluding body level; guide force reaches **1.223 kN** |
| 250 mm jump target | **Not achieved** |

The 21 cases include nominal jump, standing, a 20 mm one-wheel platform, mass
−10%/+20%, spring rate ±10%, reduced voltage, hip and wheel efficiency, reduced
current limits, motor constant and resistance changes, lower tire friction,
half timestep, softer contacts, delayed/noisy state, a combined adverse case
and two drops. The delayed case uses 5 ms delay and 0.2° RMS orientation noise;
contact events remain exact. The same gains/trajectory are used throughout,
with feedforward derived from the estimated CAD gravitational and spring energy.
The body-level failure has not been removed to make the campaign pass.
[Complete campaign](output/internal-validation/suite.json).

Two gentler follow-up trajectories still exceeded the hip range with delayed
state. A shorter launch—crouch 0.45 rad, extend 1.05 rad, retract 0.50 rad,
95 ms pulse—stays within range in its **two tested cases**: 43.3 mm nominal jump
and 50.7 mm with delayed/noisy state. The 21-case campaign has **not** been repeated
for this shorter trajectory, so it is a promising control change, not a validated
replacement operating envelope. [Watch the shorter launch](http://127.0.0.1:8765/viewer/validation.html?case=short_launch_nominal),
[two-case report](output/internal-validation/short-launch-study.json).

## Driving results

| Command and modeled resistance | Mean cruise speed | Result |
|---|---:|---|
| 0.8 m/s, no added resistance | 0.794 m/s | Tracking and stopping pass |
| 2.0 m/s, no added resistance | 1.992 m/s | Tracking and stopping pass |
| 20 km/h, no added resistance | 19.97 km/h | Tracking and stopping pass in this idealized model |
| 2.0 m/s, 2 N added resistance | 1.978 m/s | Maximum tracking-error criterion fails; stopping still passes |

These are short, flat-ground, perfect-state experiments. There is no aerodynamic
or motor-temperature model. The 20 km/h result establishes feasibility under the
stated assumptions, not a hardware rating or an off-road speed. The resistance
case uses an explicit opposing force; it is not a calibrated grass/gravel model.
[Driving replays](http://127.0.0.1:8765/viewer/validation.html?run=drive),
[driving reports](output/internal-validation/driving/suite.json).

## Structural review

Loads below come from the rigid-body simulations, not measured impacts. Simple
beam, pin and Lewis gear calculations are screening tools; they are not FEA or
fatigue ratings. The reference steel yield is 355 MPa and the provisional static
design factor is 2. Actual metal grades, fabrication and heat treatment remain
unspecified. [SSAB material reference](https://www.ssab.com/en/brands-and-products/ssab-domex/product-offer/355mc).

| Item | Finding | Disposition |
|---|---|---|
| Hip shaft → thigh | Round 8 mm shaft in an 8.2 mm round bore; no key, clamp or positive torque fastener | **Fail:** the drawing has no defined torque-transmission capacity |
| 7 mm carrier post | Nominal bending stress ≈320 MPa, yield factor ≈1.11; drop-case bending ≈508 MPa. Offset torsion can increase these demands | **Fail** against the factor-2 screen; redesign support/post and mounting |
| 60T printed hip output gear | Lewis nominal root stress ≈56 MPa at the recorded peak torque; ≈84 MPa with an assumed 1.5 load factor | **Fail** the provisional PETG screen; choose rated gearing or redesign and qualify the tooth/hub system |
| 4 mm steel guide | Net-section stress ≈49 MPa nominal / 78 MPa worst drop; nominal axial deflection ≈0.008 mm | Passes this simple static section screen only; eyes, fatigue and alignment remain unqualified |
| 6 mm knee guide pin | Simple bending estimate ≈99 MPa nominal / 157 MPa worst drop | Preliminary section margin exists for assumed 355 MPa steel; grade, fits and retention remain unqualified |
| Knee bushing / printed seat | Nominal projected pressure ≈27 MPa in the 8 × 4 mm bushing interface; printed-seat support also needs checking | Unqualified: supplier PV/pressure rating, print bearing/creep strength and alignment are missing |
| Gear/shaft/rim and knee connections | D-flat and round-bore envelopes do not complete hub strength or axial retention | Unqualified; metal load spreaders, positive torque connections and retainers need drawings |
| Spring and guide-pin retention | Spring unloads above free length; final captive rod/seats and pin retainers are absent | Unqualified; finish retention before a powered test |

For the carrier, the same simplified combined-load screen suggests roughly a
9.1 mm post for the nominal case or 10.6 mm for the worst tested drop. These are
sizing estimates, not ready-to-apply shaft dimensions: larger stock or a supported
bridge changes packaging, attachment and stress concentration and must be checked
again in CAD. The current 7 mm post has not been silently replaced in the viewer.

The gear screen uses PETG HF coupon values as a reference (34 ±4 MPa XY tensile,
23 ±4 MPa Z tensile), with a conservative 15 MPa provisional allowable. These are
not gear fatigue properties. Root fillets, print orientation, creep, temperature,
wear and actual mesh contact need a proper rating or test. [Manufacturer TDS, hosted copy](https://c.cdnmp.net/712781591/content/Bambulab_PETG_HF_Technical_Data_Sheet.pdf),
[KHK gear-rating guidance](https://khkgears.net/pdf/spur-tech.pdf).

The motor simulation also assumes a regulated bidirectional supply. Nominal
launch asks for roughly **63 A peak total bus current**, and braking briefly
returns roughly **331 W** to the modeled bus. The battery, FOC current conventions,
charge acceptance/overvoltage handling and enclosed temperature rise are not
qualified. Electrical energy/loss calculations cannot establish a continuous
current rating. [Nominal electrical and load report](output/internal-validation/jump/report.json).

## Sealing review

The enclosure **fails a CAD sealing review**: the body split has a nominal
0.4 mm gap, the hip overlap has 0.2 mm radial clearance, the knee opening has
0.4 mm radial clearance, and the spring wiper is a 0.7 mm slit in a thin membrane.
There is no complete gasket/rotary-seal/cable-gland scheme. These are open paths,
not evidence of dust or rain exclusion. No spray, dust or physical ingress test
has been performed and no IP rating is assigned.

Preserve the outer silhouette, but add captured perimeter seals, supported moving
seals or labyrinths, overlapping spring wipers and sealed cable routes. Then test
actual printed coupons and assembled closures through repeated travel and controlled
water/dust exposure. [Machine-readable structural and sealing review](output/internal-validation/structure-and-sealing.json).

## Required next design work

1. Finish positive metal hip/knee/wheel torque connections and axial/spring retention.
2. Strengthen the hip carrier and replace or qualify the printed hip transmission.
3. Reduce wheel/gear mass where actual common parts allow it; reposition components
   to improve the body equilibrium if the level-body requirement is retained.
4. Resolve launch overtravel under delay, then rerun the entire uncertainty campaign.
5. Complete the seal geometry and perform a single-leg bench test before a whole-robot jump.

For that bench test, measure masses, clearances, backlash, torque/current and
temperature using the actual prints and bought components. Apply measured loads
through the actual wheel/bearing/carrier path and inspect for permanent deformation.
The simulated drop peaks are inputs to test planning, not a prescribed proof-load
certification. Fatigue, impact variability and material coupons must establish the
eventual proof loads and duty cycle.

## Reproduce

```sh
.venv/bin/python design/concept06/internal_mass.py
.venv-sim/bin/python design/concept06/validate_internal.py
.venv-sim/bin/python design/concept06/validate_internal.py --short-launch
.venv-sim/bin/python design/concept06/validate_internal_driving.py
.venv-sim/bin/python design/concept06/check_internal_structure.py
.venv-sim/bin/python design/concept06/verify_internal_recordings.py
```

The earlier jump regression still reproduces 177.585 mm in its **old** model;
it is kept separate from these results. The campaign includes source hashes and
snapshots of its model/controller files. All computed results above remain
conditional on the stated assumptions and do not replace hardware qualification.

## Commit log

2026-09-07 Publish viewer from 89ec62fe9c2bbe7ab6c8314ba9f723c018cdf4a7
    [GM3865-3D.step, beni_cross_articulation.step, beni_enclosed_low.step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]
2026-09-07 Publish viewer from 9029d14bab8a5e3c49ae7d82b173b151e27b35b0
    [left_covered_thigh.stl, right_covered_thigh.stl]
2026-09-07 Publish viewer from 49ec45cf80d78f99d5cde2d807880566cfb45fb0
    [left_covered_thigh.stl, right_covered_thigh.stl]
2026-09-09 Publish viewer from cd21ba47d13f5c3165e8d789feed4cd98bcb4fcc
    [GM3865-3D.step, RS05.STEP, beni_cross_articulation.step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]
2026-09-10 Publish viewer from 97ea59e3279bc029fa17b03151d4ee5205f71547
    [M2p5-fasteners.stl, TPU-hub-fit-plate.stl, horizontal-bearing-plate.stl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]
